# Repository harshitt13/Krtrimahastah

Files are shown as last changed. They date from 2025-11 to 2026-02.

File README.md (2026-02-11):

# Krtrimahastah: AI-Powered Low-Cost Prosthetic Hand with intuitive multi-modal control and force feedback

**Krtrimahastah** (Sanskrit for _Artificial Hand_) is an open-source, affordable, and intelligent prosthetic arm designed to bridge the gap between expensive bionic limbs and passive cosmetic devices.

By leveraging 3D printing, the ESP32 microcontroller, AI integration, and affordable hobbyist components, this project delivers a fully functional, multi-modal assistive device for under **$100 USD**.

Watch the video on YouTube: [https://youtu.be/Tq0eUJswGTI](https://youtu.be/Tq0eUJswGTI)

Watch the demonstration video on YouTube: [https://youtu.be/BNZyQIecj14](https://youtu.be/BNZyQIecj14)

---

## Table of Contents

- [Key Features](#key-features)
- [Project Overview](#project-overview)
- [Hardware Architecture](#hardware-architecture)
- [Pinout Reference](#pinout-reference)
- [System Architecture & Connection Flow](#system-architecture--connection-flow)
- [3D Model Components](#3d-model-components)
- [Wire Mapping](#wire-mapping)
- [Electrical Schematic](#electrical-schematic)
- [Control Logic](#control-logic)
- [Software Setup](#software-setup)
- [Installation & Setup](#installation--setup)
- [Usage Guide](#usage-guide)
- [File Structure](#file-structure)
- [Learning Resources](#learning-resources)
- [License](#license)
- [Disclaimer & Safety Notice](#%EF%B8%8F-disclaimer--safety-notice)
- [Contact & Support](#contact--support)

---

## Key Features

### **Multi-Modal Control System**

- **Voice Commands (Primary):** Integrated with SinricPro IoT platform for voice control via Alexa/Google Assistant
- **EMG Muscle Signals (Secondary):** Backup EMG-based control for silent/offline operation with binary toggle (Open ↔ Close)
- **Smart Home Integration:** Connect to Amazon Alexa or Google Home for hands-free gesture commands

### **Intelligent Hardware**

- **Tendon-Driven Actuation:** Bio-inspired mechanical design with 5 independent MG90s servos for anthropomorphic finger movement
- **Haptic Feedback System:** Force Sensitive Resistors (FSRs) in fingertips enable closed-loop grip control, preventing crushing of delicate objects
- **Haptic Force Sensing:** Real-time pressure monitoring (max grip force: 2000 units with safety cutoff)

### **Power Management Innovation**

- **All-Day Portability:** Power bank with optimized power splitting:
  - **High-Power Rail:** 5V for servo actuation (high current spikes)
  - **Logic Rail:** 3.3V via ESP32 regulator (low current, noise-isolated)

### **Cost-Effective Engineering**

- Built entirely with off-the-shelf hobbyist components
- FDM 3D printing for structural parts (PLA material)
- Total BOM cost under $100 USD
- Open-source firmware for transparency and community contribution

### **Safety Features**

- Pressure/tactile feedback prevents over-gripping
- Software watchdog timer (10-second timeout)
- EMG debounce protection (200ms)
- Safety state machine for graceful error handling
- Servo angle constraints to prevent mechanical damage

---

## Project Overview

### **Problem Statement**

Prosthetic limbs remain inaccessible to the majority due to prohibitive costs ($3,000-$100,000+). This project demonstrates that functional bionic devices can be built affordably using modern open-source hardware and AI.

### **Solution**

A modular, 3D-printed prosthetic hand that combines:

- **Affordable actuation:** MG90s servo motors instead of expensive linear actuators
- **Intelligent control:** AI-based language processing with offline fallback
- **Biological feedback:** FSR-based haptic sensing for dexterous manipulation
- **Energy efficiency:** Optimized power management for all-day wearability

---

## Hardware Architecture

| Component | Quantity | Function |
| :--- | :---: | :--- |
| **ESP32 DevKit V1** | 1 | Main microcontroller (32-bit dual-core, Wi-Fi/BLE) |
| **MG90s Servo Motor** | 5 | Individual finger actuators (180° range, 1.5kg torque) |
| **SinricPro Account** | 1 | IoT cloud service for voice control integration |
| **EMG Sensor Module V3.0** | 1 | Muscle signal acquisition (3-channel, 10-bit ADC) |
| **FSR402 Pressure Sensor** | 2 | Tactile feedback in thumb & index finger |
| **10K Ohm Resistors** | 2 | Volatge Divider for FSR Sensor |
| **3D Printed Parts** | — | PLA chassis (hand, phalanges, forearm cover) |
| **Servo Horns & Hardware** | — | Servo linkages & fasteners |
| **USB-C Cable & Connectors**  | — | Power delivery & debugging |
| **Breadboard & Jumper Wires** | — | Prototyping & connections |

---

## Pinout Reference

### **ESP32 GPIO Pin Allocation**

| Component | Signal Line | ESP32 GPIO | Pin Type | Notes |
| :--- | :--- | :---: | :--- | :--- |
| **SERVO: Thumb** | PWM Signal |  GPIO 13 | OUTPUT | Channel 0, PWM (0-180°) |
| **SERVO: Index** | PWM Signal |  GPIO 12 | OUTPUT | Channel 1, PWM (0-180°) |
| **SERVO: Middle**  | PWM Signal |  GPIO 14 | OUTPUT | Channel 2, PWM (0-180°) |
| **SERVO: Ring** | PWM Signal |  GPIO 27 | OUTPUT | Channel 3, PWM (0-180°) |
| **SERVO: Pinky** | PWM Signal |  GPIO 26 | OUTPUT | Channel 4, PWM (0-180°) |
| **EMG Sensor** | Analog Output |  GPIO 34 | ADC1 INPUT | 0-4095 (3.5-18V) muscle signal  |
| **FSR: Thumb Tip** | Analog Output |  GPIO 36 | ADC1 INPUT | Pressure sensing (0-2000 units) |
| **FSR: Index Tip** | Analog Output |  GPIO 39 | ADC1 INPUT | Pressure sensing (0-2000 units) |

### **Servo Angle Limits**

| Finger | Min Angle (Open) | Max Angle (Closed) | Movement Range |
| :----- | :---: | :---: | :---: |
| Thumb  | 0° | 120° | 120° |
| Index  | 0° | 175° | 175° |
| Middle | 0° | 175° | 175° |
| Ring | 0° | 175° | 175° |
| Pinky  | 0° | 175° | 175° |

---

## System Architecture & Connection Flow

### **Overall System Architecture**

```mermaid
graph TB
    subgraph "Input Layer"
        VOICE["Voice Input<br/>Alexa/Google Assistant"]
        EMG["EMG Sensor<br/>Muscle Signals"]
        FSR["FSR Sensors<br/>Tactile Feedback"]
    end

    subgraph "Processing Layer"
        ESP32["ESP32 DevKit<br/>Main Microcontroller<br/>Dual-Core 240MHz"]
        WIFI["Wi-Fi Module<br/>802.11 b/g/n"]
        SINRIC["SinricPro<br/>IoT Cloud Service"]
    end

    subgraph "Control Logic"
        FSM["State Machine<br/>5 Operating Modes"]
        SERVO_CTRL["Servo Controller<br/>PWM Generator"]
        SAFETY["Safety Module<br/>Watchdog & Limits"]
    end

    subgraph "Output Layer"
        THUMB["Thumb Servo<br/>GPIO 13"]
        INDEX["Index Servo<br/>GPIO 12"]
        MIDDLE["Middle Servo<br/>GPIO 14"]
        RING["Ring Servo<br/>GPIO 27"]
        PINKY["Pinky Servo<br/>GPIO 26"]
    end

    subgraph "Power Distribution"
        BATTERY["Power Bank"]
        SERVO_RAIL["Servo Rail (5V)<br/>High Current"]
        LOGIC_RAIL["Logic Rail (3.3V)<br/>Low Noise"]
    end

    VOICE --> SINRIC
    EMG --> ESP32
    FSR --> ESP32
    ESP32 --> WIFI
    WIFI --> SINRIC
    SINRIC --> ESP32
    ESP32 --> FSM
    FSM --> SERVO_CTRL
    FSR --> SAFETY
    SERVO_CTRL --> SAFETY
    SAFETY --> THUMB
    SAFETY --> INDEX
    SAFETY --> MIDDLE
    SAFETY --> RING
    SAFETY --> PINKY
    BATTERY --> SERVO_RAIL
    BATTERY --> LOGIC_RAIL
    SERVO_RAIL --> THUMB
    SERVO_RAIL --> INDEX
    SERVO_RAIL --> MIDDLE
    SERVO_RAIL --> RING
    SERVO_RAIL --> PINKY
    LOGIC_RAIL --> ESP32
    LOGIC_RAIL --> FSR
    SERVO_RAIL --> EMG
```

### **Control Flow & State Machine Diagram**

```mermaid
stateDiagram-v2
    [*] --> IDLE

    IDLE --> EMG_CONTROL: System Initialized

    EMG_CONTROL --> GESTURE: Voice trigger + Valid command
    EMG_CONTROL --> GESTURE: EMG muscle flex detected

    GESTURE --> EMG_CONTROL: Gesture complete

    EMG_CONTROL --> SAFETY_STOP: FSR limit exceeded<br/>OR EMG overload<br/>OR Watchdog timeout
    SAFETY_STOP --> EMG_CONTROL: User releases grip<br/>Safety reset triggered

    EMG_CONTROL --> [*]: Shutdown signal
```

### **Data Flow: Voice Command Pipeline**

```mermaid
sequenceDiagram
    User->>Google Assistant: Speak voice command<br/>("Hey Google, turn on Prosthetic Hand")
    Google Assistant->>SinricPro: Process & forward command
    SinricPro->>ESP32: Send gesture command via WebSocket
    ESP32->>ESP32: Parse mode command<br/>(e.g., "Prosthetic Hand", "peace", "point")
    ESP32->>SERVO_CTRL: Calculate target angles
    SERVO_CTRL->>THUMB: Write PWM signal (GPIO 13)
    SERVO_CTRL->>INDEX: Write PWM signal (GPIO 12)
    SERVO_CTRL->>MIDDLE: Write PWM signal (GPIO 14)
    SERVO_CTRL->>RING: Write PWM signal (GPIO 27)
    SERVO_CTRL->>PINKY: Write PWM signal (GPIO 26)
    SERVO_CTRL->>FSR: Monitor pressure (GPIO 36, 39)
    FSR->>SAFETY: Pressure threshold check
    SAFETY->>User: Haptic feedback (grip achieved)
```

### **Power Management & Rail Isolation**

```mermaid
graph LR
    BATTERY["<br/>Dual USB Output"]

    USB1["USB Port 1<br/>5V Output"]
    USB2["USB Port 2<br/>5V Output"]

    SERVO_POWER["Servo Rail Breadboard<br/>5V Direct<br/>500mA+"]
    LOGIC_POWER["Logic Rail Breadboard<br/>5V → ESP32 Regulator<br/>→ 3.3V<br/>100mA clean"]

    SERVO_DRAWS["Servo Power Draws:<br/>• Idle: 5-10mA/servo + EMG<br/>• Active: 100-200mA/servo<br/>• Peak: 500mA (all 5)"]

    LOGIC_DRAWS["Logic Power Draws:<br/>• ESP32: 80-160mA<br/>• FSR: 10-15mA<br/>• Total: ~140mA"]

    BATTERY --> USB1
    BATTERY --> USB2
    USB1 --> SERVO_POWER
    USB2 --> LOGIC_POWER
    SERVO_POWER --> SERVO_DRAWS
    LOGIC_POWER --> LOGIC_DRAWS

```

---

## 3D Model Components

### **Hand Assembly Structure**

[Hand Layout Reference (STL)](hardware/3d-models/Hand%20Layout.stl)
_Reference: Complete hand assembly layout showing all finger components and palm structure_

The prosthetic hand consists of **8 3D-printed parts** designed for FDM printing (PLA material):

| Component | File Name | Material |
| :--- | :--- | :---: |
| **Palm/Metacarpal** | `Hand.stl` | PLA |
| **Thumb Digit** | `Finger_Thumb.stl`  | PLA |
| **Index Finger** | `Finger_Index.stl`  | PLA |
| **Middle Finger** | `Finger_Middle.stl` | PLA |
| **Ring Finger** | `Finger_Ring.stl` | PLA |
| **Pinky Finger** | `Finger_Pinky.stl`  | PLA |
| **Arm Cover** | `Arm_Cover.stl` | PLA |
| **Right Hand** | `Right_Hand.stl` | PLA |

### **3D Printing Recommendations**

```
Printer Settings:
├─ Nozzle Temperature: 210°C (PLA)
├─ Bed Temperature: 60°C
├─ Layer Height: 0.2mm (0.1mm for finger tips for detail)
├─ Infill: 40% (gyroid pattern for strength/weight ratio)
├─ Support: Yes (especially for finger undercuts)
├─ Print Speed: 50mm/s
├─ Total Print Time: ~40 hours
└─ Material Weight: ~250g PLA filament
```

### **Assembly Instructions**

1. Print all components with support structures
2. Remove supports carefully (palm/finger joints are delicate)
3. Assemble fingers and attch to plam pivto points using 0.5mm fishing wire (for retarcking) and 2mm elastic string (for flexibility)
4. Use super glue attach servos in palm housing
5. Connect servo horns to finger linkages via fishing wire
6. Mount arm cover shell with servo motor peeking through rear cavity
7. Route wiring through forearm to the circuit
8. Perform mechanical range-of-motion test before powering (zeroing all the motors while fingers are opened)

---

## Wire Mapping

### **Connection Matrix: Sensors ↔ ESP32**

**Detailed wiring documentation available in:** [Wire Mapping](hardware/wiring/Wire%20Mapping%20for%20the%20Development%20of%20a%20Low-Cost%20Prosthetic%20Hand%20%281%29.xlsx)

### **Quick Wire Reference (5V Servos)**

```
┌─────────────────────────────────────────────┐
│              SERVO CONNECTIONS              │
├──────────────┬──────────┬───────────────────┤
│ Servo Motor  │ ESP32    │ Function          │
├──────────────┼──────────┼───────────────────┤
│ Thumb        │ GPIO 13  │ PWM Output        │
│ Index        │ GPIO 12  │ PWM Output        │
│ Middle       │ GPIO 14  │ PWM Output        │
│ Ring         │ GPIO 27  │ PWM Output        │
│ Pinky        │ GPIO 26  │ PWM Output        │
│ GND (All)    │ GND      │ Common ground     │
│ +5V (All)    │ +5V Rail │ Servo power rail  │
└──────────────┴──────────┴───────────────────┘
```

### **Sensor Wire Connections**

```
┌─────────────────────────────────────────────────────────────┐
│              SENSOR & INPUT CONNECTIONS                     │
├──────────────────┬──────────┬──────────┬────────────────────┤
│ Component        │ Signal   │ ESP32    │ Type               │
├──────────────────┼──────────┼──────────┼────────────────────┤
│ EMG Sensor       │ SIG      │ GPIO 34  │ Analog Input (ADC) │
│ FSR Thumb        │ SIG      │ GPIO 36  │ Analog Input (ADC) │
│ FSR Index        │ SIG      │ GPIO 39  │ Analog Input (ADC) │
│ All Sensors      │ GND      │ GND      │ Common ground      │
│ EMG Sensors (+ve)│ +5V      │ +5V Rail │ Servo power rail   │
│ Both FSR Sensors │ +3.3V    │ 3.3V     │ Logic power        │
└──────────────────┴──────────┴──────────┴────────────────────┘
```

### **SinricPro Voice Integration**

```
Alexa/Google Assistant → SinricPro Cloud → WebSocket → ESP32
│
├─ Supported Gestures: 20+ hand poses
├─ Protocol: WebSocket (persistent connection)
├─ Commands: Natural language ("open hand", "make a fist", "point")
├─ Response Time: ~200-500ms (cloud processing)
└─ Offline Fallback: EMG sensor toggle control
```

---

## Electrical Schematic

### **Schematic Diagram**

<p align="center">
  <a href="hardware/schematics/Prosthetci%20Hand%20Schematic.png">
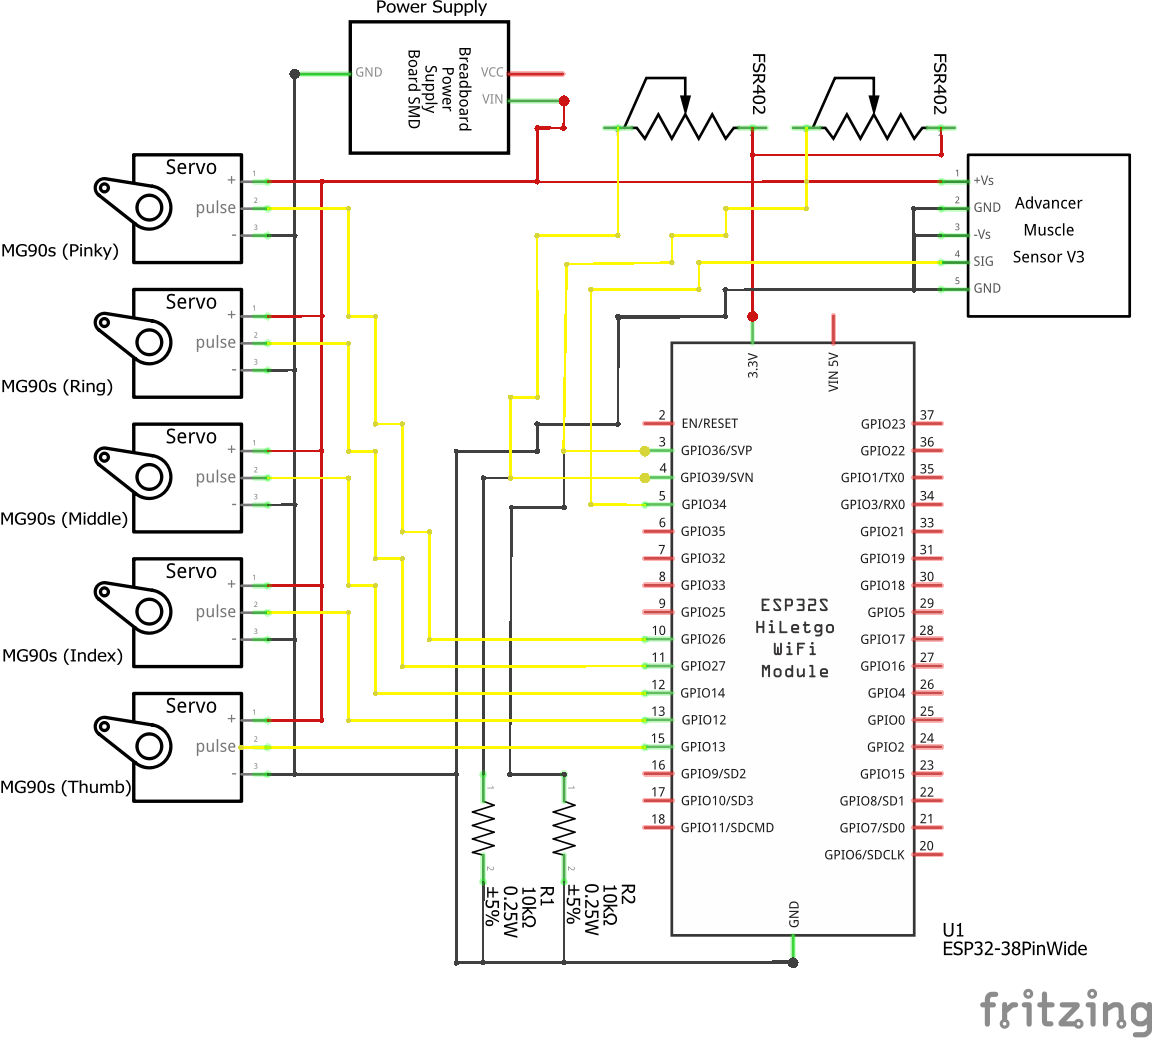
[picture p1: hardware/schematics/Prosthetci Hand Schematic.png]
    
  </a>
</p>

### **Power Distribution**

```
┌──────────────────────────────────────────────────────────────────┐
│                    POWER DISTRIBUTION SYSTEM                     │
├──────────────────────────────────────────────────────────────────┤
│                                                                  │
│  Power Bank (Dual Output)                                        │
│  ├─ USB Port 1 (5V, 3A) ──► SERVO POWER RAIL (5V, 500mA+)        │
│  │                         ├─► MG90s Servo 1 (GPIO 13)           │
│  │                         ├─► MG90s Servo 2 (GPIO 12)           │
│  │                         ├─► MG90s Servo 3 (GPIO 14)           │
│  │                         ├─► MG90s Servo 4 (GPIO 27)           │
│  │                         ├─► MG90s Servo 5 (GPIO 26)           │
│  │                         └─► EMG Sensor V3.0 (GPIO 34)         │
│  │                                                               │
│  └─ USB Port 2 (3.3V, 1A) ──► LOGIC POWER RAIL (3.3V via ESP32)  │
│                              └─ ESP32 DevKit                     │
│                                 ├─ Wi-Fi Module (SinricPro)      │
│                                 ├─ EMG Sensor V3.0               │
│                                 └─ FSR402 Sensors (GPIO 36, 39)  │
│                                                                  │
└──────────────────────────────────────────────────────────────────┘
```

### **Voltage Levels & Current Budget**

```
┌────────────────────────────────────────────────────────┐
│            POWER CONSUMPTION ANALYSIS                  │
├────────────────────────────────────────────────────────┤
│                                                        │
│ SERVO RAIL (5V):                                       │
│  • Idle (all open):        25-50mA    (~250mW)         │
│  • Single servo active:   100-150mA   (~750mW)         │
│  • All servos moving:     400-600mA   (~3W)            │
│  • Peak grip (all tight):  600-800mA  (~4W)            │
│                                                        │
│ LOGIC RAIL (3.3V @ ESP32):                             │
│  • ESP32 idle:             80-100mA                    │
│  • Wi-Fi active:          150-200mA (peak)             │
│  • EMG + FSR Sensors:      10-15mA                     │
│  • Total logic:            140-220mA                   │
│                                                        │
│ BATTERY RUNTIME (Estimated):                           │
│  • Idle (servos open):     ~100 hours                  │
│  • Mixed use (50% active): ~12-15 hours                │
│  • Heavy use (all moving): ~5-7 hours                  │
│                                                        │
└────────────────────────────────────────────────────────┘
```

---

## Control Logic

### **Operating Modes**

#### **Mode 1: EMG Toggle Control (Offline)**

- **Activation:** Muscle flex detected by EMG sensor
- **Logic:** Binary toggle (Open ↔ Close)
- **Use Case:** Rapid, frequent actions; no voice needed
- **Reliability:** High (no network dependency)

```
EMG Signal → Threshold Detection → Debounce (200ms)
  → State Toggle → Servo Movement → 2-3s Animation → Return to Idle
```

#### **Mode 2: Voice Command Control (Online)**

- **Activation:** Voice command via Alexa or Google Assistant
- **Processing Pipeline:**
  1. User speaks to Google Assistant: "Hey Google, turn on Prosthetic Hand" or "Hey Google, set prosthetic hand to Peace"
  2. SinricPro cloud processes command via WebSocket
  3. ESP32 receives gesture mode string (e.g., "fist", "peace", "point")
  4. Execute corresponding servo movement pattern
- **Supported Commands:** 20+ gestures including "Prosthetic Hand," "Point," "Peace," "Hook," "Thumbs Up," "OK," "Gun,"

#### **Mode 3: Closed-Loop Grip**

- **Purpose:** Prevent over-gripping & crushing delicate objects
- **Implementation:**
  - FSR sensors in fingertips detect force
  - Once force exceeds threshold (2000 units), grip stops tightening
  - Maintains constant pressure automatically

---

## Software Setup

### **Prerequisites**

- **Arduino IDE** ([Download](https://www.arduino.cc/en/software))
- **ESP32 Board Support** installed via Board Manager
- **SinricPro Account** (Free) - Create at [https://sinric.pro](https://sinric.pro)
- **Amazon Alexa or Google Home** device (or mobile app)
- **Wi-Fi Network** with 2.4GHz support (5GHz not recommended for ESP32)

### **Required Libraries**

Install via Arduino Library Manager (`Sketch → Include Library → Manage Libraries`):

| Library | Author | Purpose |
| :--- | :--- | :--- |
| `ESP32Servo`  | Kevin Harrington | PWM servo control for MG90s motors |
| `SinricPro` | Boris Jaeger | IoT cloud integration for voice control |
| `WebSockets`  | Markus Sattler | WebSocket communication with SinricPro  |
| `ArduinoJson` | Benoit Blanchon  | JSON parsing for SinricPro messages |

### **SinricPro Setup**

1. Create a free account at [https://sinric.pro](https://sinric.pro)

2. Create a new **Device Template** → Select "Speaker" device type

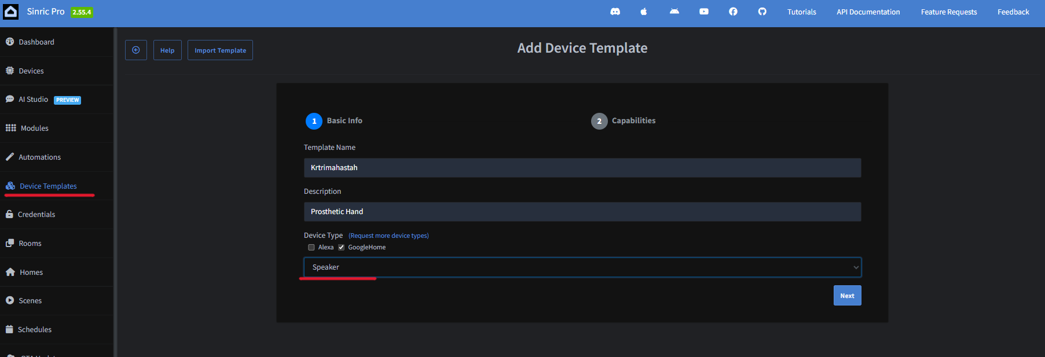
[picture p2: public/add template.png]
Add template device
   

3. Add two capabilities: "Power" & "Mode". Configure "Mode" Capability

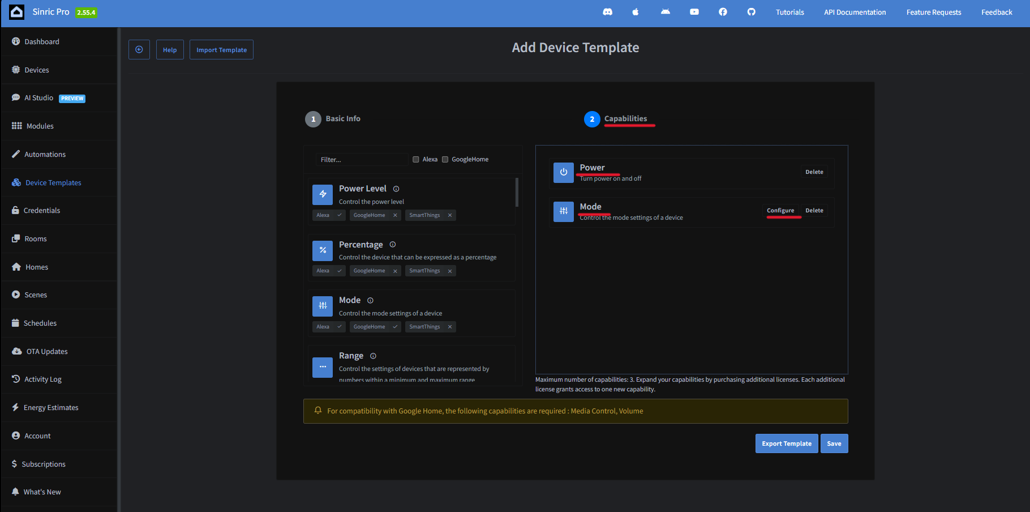
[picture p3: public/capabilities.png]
Capabilities configuration
   
   - Set "Instance Id" & "Mode Name" as shown in the photo

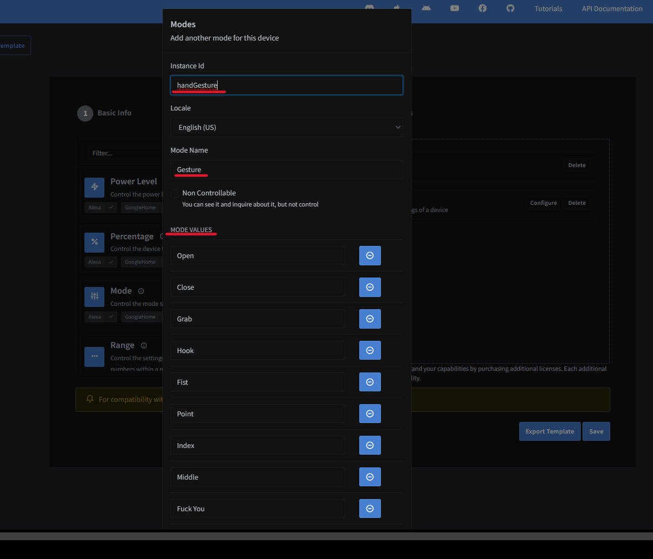
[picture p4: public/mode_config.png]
Mode configuration
     

   - Save the template

4. Create a new **Device** → Select "Krtrimahastah_Template" device type

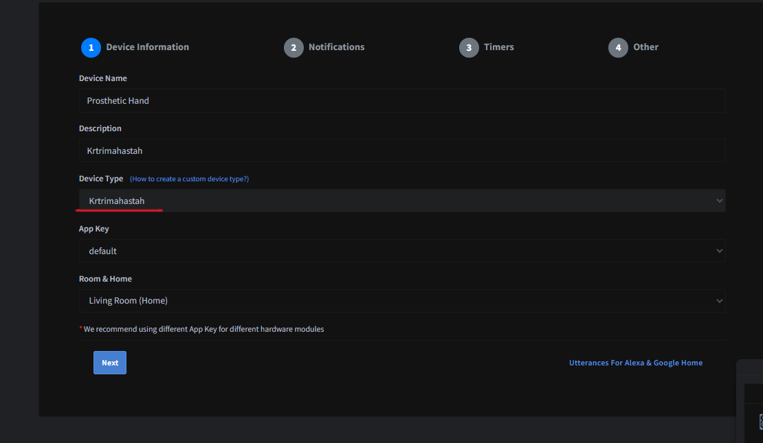
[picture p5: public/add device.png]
Add device
   

5. Note your credentials:
   - **APP_KEY** - Found in "Credentials" section
   - **APP_SECRET** - Found in "Credentials" section
   - **DEVICE_ID** - Found in your device settings

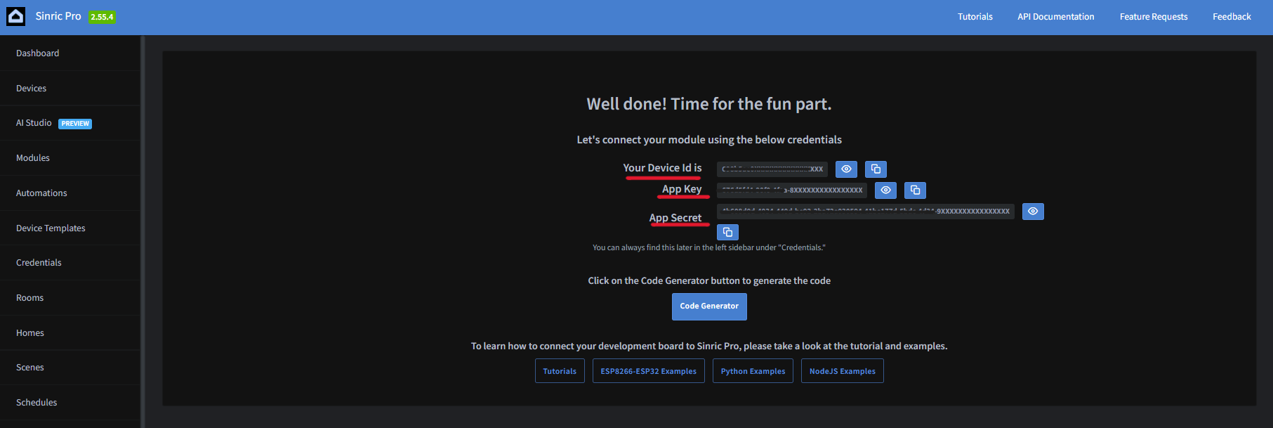
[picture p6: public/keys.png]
API Keys
     

6. Link SinricPro to **Amazon Alexa** or **Google Home**:
   - Open Alexa/Google Home app
   - Search for "SinricPro" skill and enable
   - Discover devices

7. Add credentials to firmware configuration

---

## Installation & Setup

### **Step 1: Prepare Hardware**

```bash
1. Assemble 3D-printed hand structure (see 3D Model Components)
2. Mount 5 MG90s servos inside palm housing
3. Attach servo horns to finger linkages
4. Solder power supply rails on breadboard (5V servo, 3.3V logic)
5. Wire all components according to Master Pinout (see Wire Mapping section)
6. Mount ESP32 DevKit inside arm cover
7. Connect power bank via USB cables
8. Perform visual inspection for short circuits
```

### **Step 2: Prepare Firmware**

```bash
# Clone the repository
git clone https://github.com/harshitt13/Krtrimahastah.git
cd Krtrimahastah

# Open Arduino IDE
1. File → Open → firmware/prosthetic_hand_improved.ino
2. Board: ESP32 Dev Module
3. Port: COM3 (or your ESP32 port)
```

### **Step 3: Configure Credentials**

Edit [main/main.ino](main/main.ino) and update:

```cpp
#define WIFI_SSID         "Your_Wi-Fi_SSID"
#define WIFI_PASS         "Your_Wi-Fi_Password"

#define APP_KEY           "YOUR_APP_KEY"     // From SinricPro Dashboard
#define APP_SECRET        "YOUR_APP_SECRET"  // From SinricPro Dashboard
#define DEVICE_ID         "YOUR_DEVICE_ID"   // From your SinricPro device
```

### **Step 4: Upload & Test**

```
1. Verify code (Sketch → Verify)
2. Upload to ESP32 (Sketch → Upload)
3. Open Serial Monitor (Tools → Serial Monitor, 115200 baud)
4. Press Reset button on ESP32
5. Observe startup messages and Wi-Fi connection
6. Say "Hey Google, discover devices" to find your prosthetic hand
7. Test voice commands: "Hey Google, turn on Prosthetic Hand"
8. Test EMG mode by flexing muscles
9. Verify all 5 fingers move smoothly
```

### **Step 5: Calibration**

```cpp
EMG Sensor Tuning:
├─ Flex muscle & note ADC reading
└─ Set EMG_THReshold to ADC reading

FSR Sensor Tuning:
├─ Press fingertip & note ADC reading
├─ Set FSR_LIMIT to safe threshold (default 4000)
└─ Test grip on soft object to verify cutoff

Servo Angle Tuning:
├─ Adjust MAX_TP (thumb & pinky angle)
├─ Adjust MAX_OTHERS (index, middle, ring finger angle)
└─ Test all gestures for smooth motion
```

---

## Usage Guide

### **Voice Control (via Alexa/Google Assistant)**

```
1. Say "Hey Google, turn on Prosthetic Hand" or "Hey Google, set prosthetic hand to peace"
2. SinricPro processes command and sends to ESP32
3. Hand executes the gesture smoothly
4. Stays in gesture until new command or EMG override

Supported Hey Google Commands:

Functional Gestures:
├─ "Hey Google, turn on/off Prosthetic Hand"                   → ON/OFF Prosthetic Hand
├─ "Hey Google, set prosthetic hand to Hook"                   → Hook grip (all fingers curled except thumb)
└─ "Hey Google, set prosthetic hand to Grab"                   → Grab the object (All fingers closed)

Social Gestures:
├─ "Hey Google, set prosthetic hand to Open"                   → All fingers extended
├─ "Hey Google, set prosthetic hand to Point"                  → Index finger pointing
├─ "Hey Google, set prosthetic hand to Two"                    → Peace sign (index + middle)
├─ "Hey Google, set prosthetic hand to Three"                  → Three fingers up
├─ "Hey Google, set prosthetic hand to Four"                   → Four fingers up
├─ "Hey Google, set prosthetic hand to Thumbs Up"              → Thumbs up gesture
├─ "Hey Google, set prosthetic hand to OK"                     → OK sign (thumb + index circle)
├─ "Hey Google, set prosthetic hand to Love"                   → there's no love, forget her bro
├─ "Hey Google, set prosthetic hand to Gun"                    → Finger gun
├─ "Hey Google, set prosthetic hand to Call"                   → Call me gesture
├─ "Hey Google, set prosthetic hand to Fuck Off"               → no one have enemies
└─ "Hey Google, set prosthetic hand to Pinky"                  → Pinky promise

Control:
├─ "Hey Google, turn on Hand"                                  → Enable EMG control
└─ "Hey Google, turn off Hand"                                 → Disable EMG control
```

### **EMG Control**

```
1. Ensure EMG sensor strap is worn around forearm
2. Relax arm at rest
3. Flex muscle briefly (1-2 second contraction)
4. Hand gesture toggles (Open ↔ Close)
5. No voice required; works offline

Gesture Sequence:
├─ Open → Flex → Close
├─ Close → Flex → Open
└─ Debounce: 200ms (ignores multiple quick flexes)
```

### **Emergency Stop**

```
Safety is automatic via FSR sensors:
→ If FSR detects force > 4000 units, fingers stop automatically
→ Triggers SAFETY_STOP state
→ All fingers will stop at their current position and will only move if the sensor detects less force or either it's an opening command.

Manual Reset:
→ Send "Open" command via Hey Google
→ Or use EMG sensor to toggle open
```

---

## File Structure

```
Krtrimahastah/
├── .dist/                                     # Build output (if present)
├── README.md                                  # Project documentation
├── LICENSE                                    # MIT License
├── main/
│   └── main.ino                               # Main ESP32 firmware (682 lines)
├── public/                                    # Static assets (if present)
└── hardware/
  ├── 3d-models/
  │   ├── Hand Layout.stl                     # Full assembly reference
  │   ├── Hand.stl                            # Palm structure
  │   ├── Finger_Thumb.stl                    # Thumb digit
  │   ├── Finger_Index.stl                    # Index finger
  │   ├── Finger_Middle.stl                   # Middle finger
  │   ├── Finger_Ring.stl                     # Ring finger
  │   ├── Finger_Pinky.stl                    # Pinky finger
  │   ├── Arm_Cover.stl                       # Forearm enclosure
  │   ├── Hand_print_layout.stl               # Print nesting guide
  │   └── Right_Hand.stl                      # Mirror version
  ├── schematics/
  │   └── Prosthetci Hand Schematic.png       # Circuit diagram
  └── wiring/
    └── Wire Mapping for the Development of a Low-Cost Prosthetic Hand.xlsx # Detailed pinout & connection matrix

```

---

## Learning Resources

- **ESP32 Documentation:** [https://docs.espressif.com/projects/esp-idf/](https://docs.espressif.com/projects/esp-idf/)
- **SinricPro Documentation:** [https://sinricpro.github.io/esp8266-esp32-sdk/](https://sinricpro.github.io/esp8266-esp32-sdk/)
- **Servo Motor Control:** [https://randomnerdtutorials.com/esp32-servo-motor/](https://randomnerdtutorials.com/esp32-servo-motor/)
- **Myoware Muscle Sensor User-Manual** [https://robu.in/wp-content/uploads/2019/02/Muscle-Sensor-v3-Users-Manual.pdf/](https://robu.in/wp-content/uploads/2019/02/Muscle-Sensor-v3-Users-Manual.pdf)

---

## License

This project is licensed under the **MIT License** - see the [LICENSE](LICENSE) file for details.

Permission is granted for personal, educational, and commercial use with proper attribution.

---

## ⚠️ Disclaimer & Safety Notice

**IMPORTANT:** This is a **research prototype** and **NOT a medically certified device**.

### **Usage Warnings:**

- ⚠️ Not intended for medical/therapeutic use without proper regulatory approval
- ⚠️ Strength and safety capabilities vary widely based on component quality and assembly accuracy
- ⚠️ Do not use with high-pressure/high-risk gripping tasks
- ⚠️ Servo motors can pinch fingers; always supervise use around children
- ⚠️ Battery may overheat if damaged; inspect regularly for swelling
- ⚠️ Wi-Fi connectivity may drop; EMG control serves as offline backup
- ⚠️ Test all safety features before extended use

### **Liability:**

The author and contributors assume **NO LIABILITY** for injuries, property damage, or adverse outcomes resulting from the use or misuse of this device.

---

## Contact & Support

- **GitHub Issues:** [Report bugs or request features](https://github.com/harshitt13/Krtrimahastah/issues)
- **Email:** find.harshitkushwaha@gmail.com

---

_Making prosthetics affordable, intelligent, and accessible to all._ 🤖

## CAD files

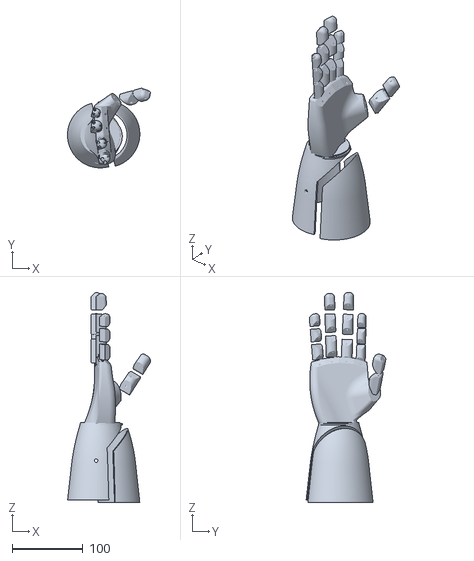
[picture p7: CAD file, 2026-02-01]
hardware/3d-models/Hand Layout.stl
117.5 x 113.1 x 297.7

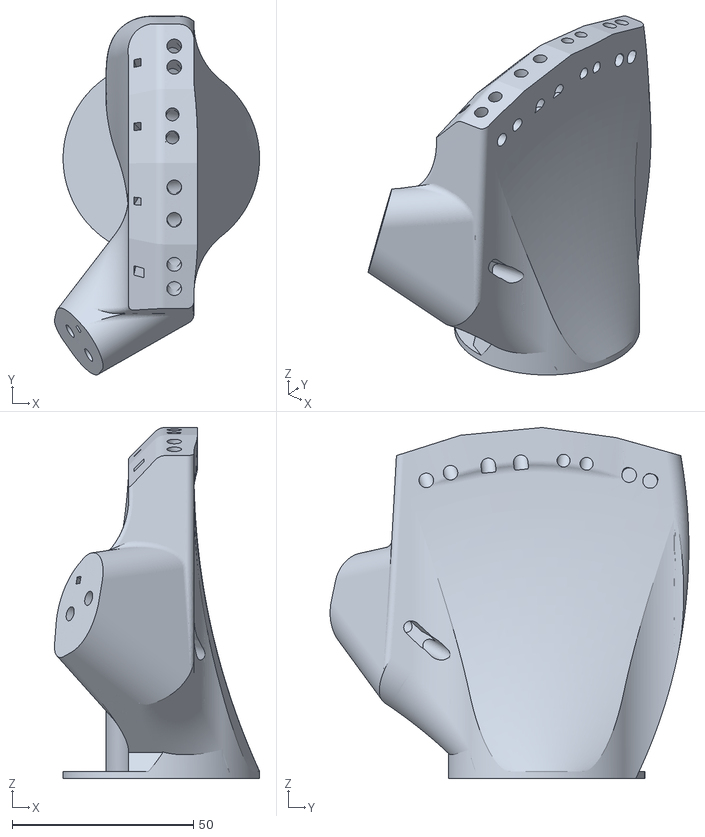
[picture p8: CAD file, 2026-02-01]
hardware/3d-models/Right_Hand.stl
56.5 x 98.9 x 96.8

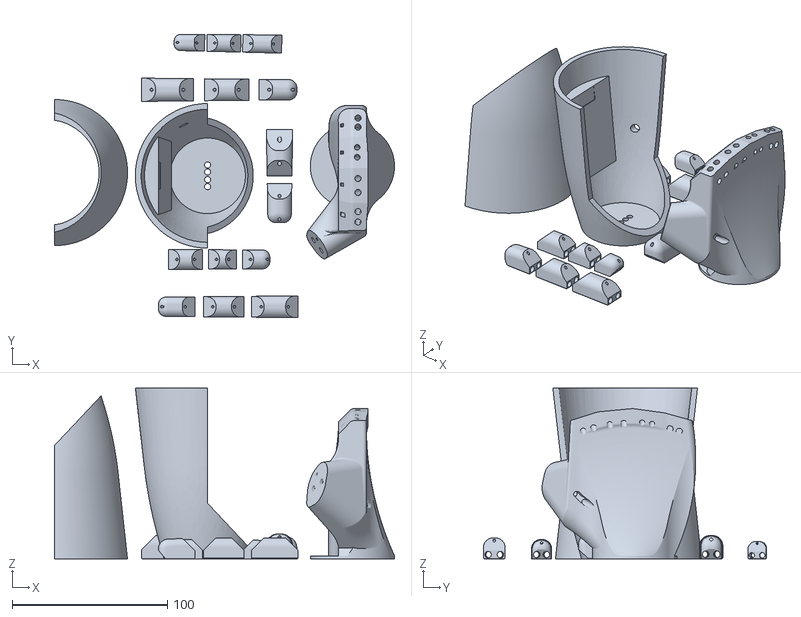
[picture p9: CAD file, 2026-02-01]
hardware/3d-models/Hand_print_layout.stl
218.8 x 182.3 x 109.9

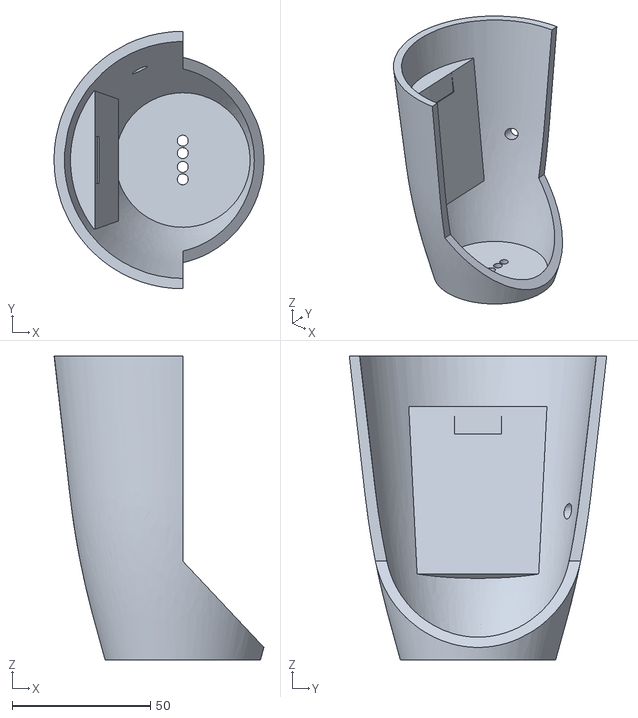
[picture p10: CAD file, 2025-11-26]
hardware/3d-models/Hand.stl
75.9 x 93.1 x 109.9

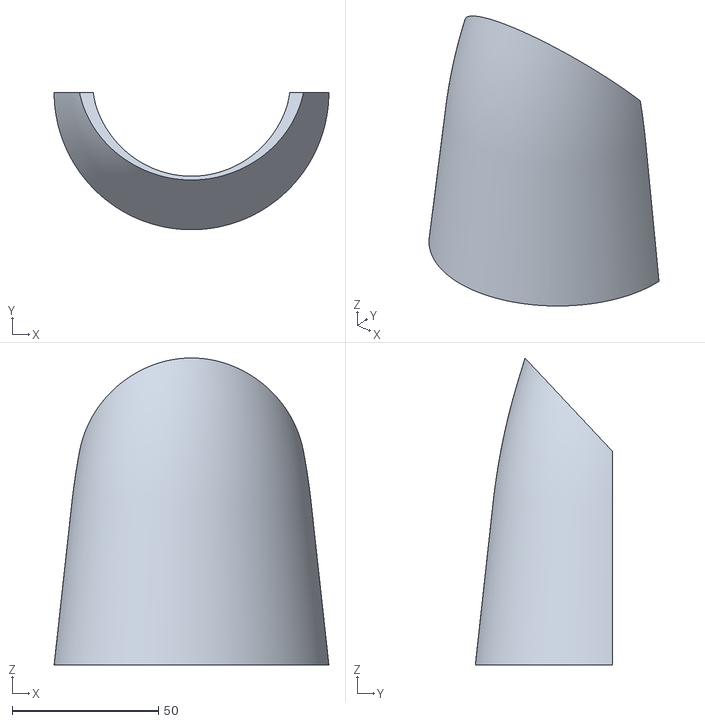
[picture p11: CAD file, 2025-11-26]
hardware/3d-models/Arm_Cover.stl
94.0 x 47.0 x 105.0

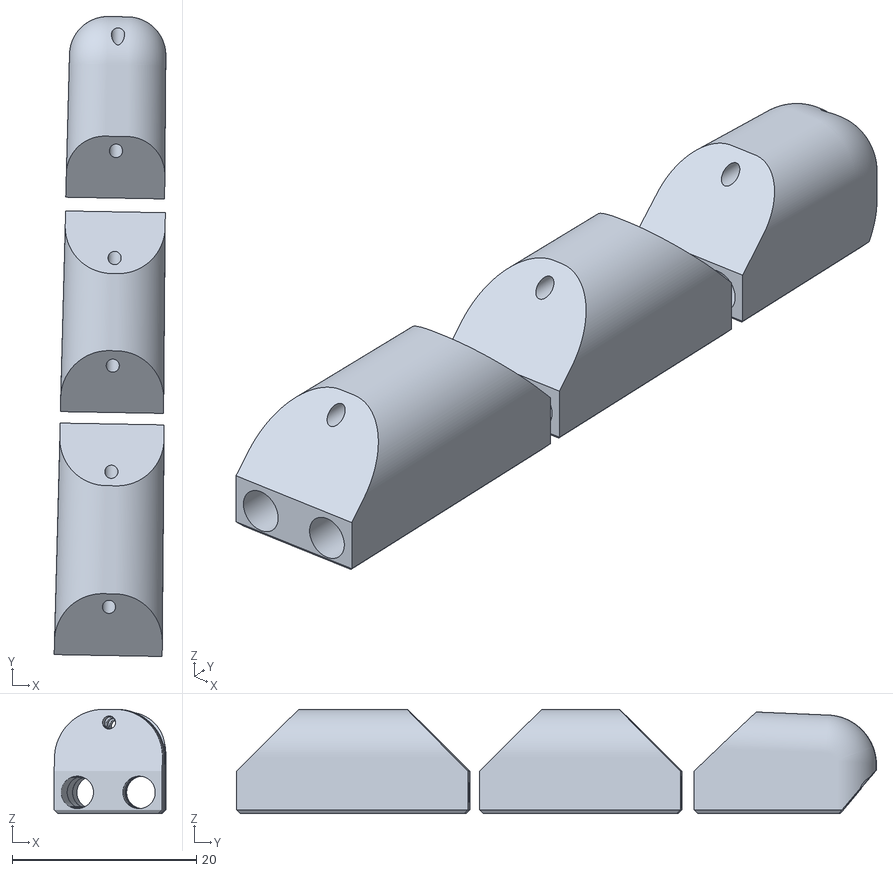
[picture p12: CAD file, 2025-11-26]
hardware/3d-models/Finger_Index.stl
12.1 x 69.4 x 11.3

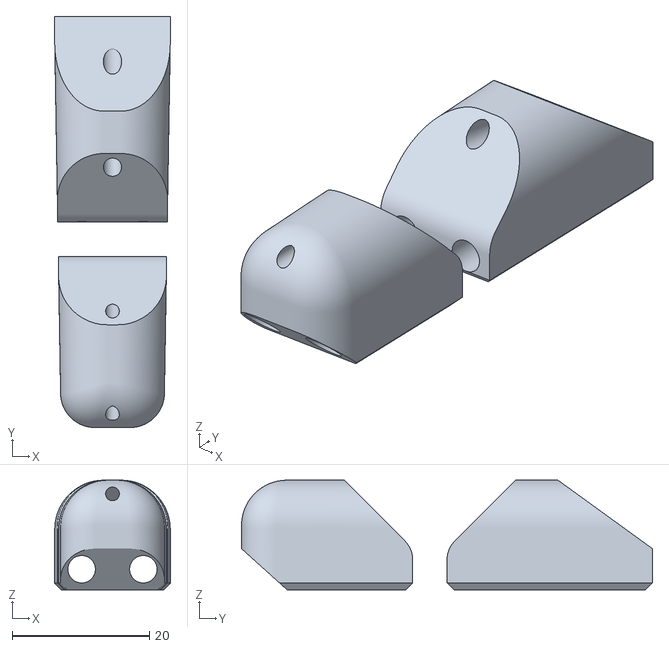
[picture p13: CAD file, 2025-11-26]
hardware/3d-models/Finger_Thumb.stl
17.0 x 60.0 x 16.0

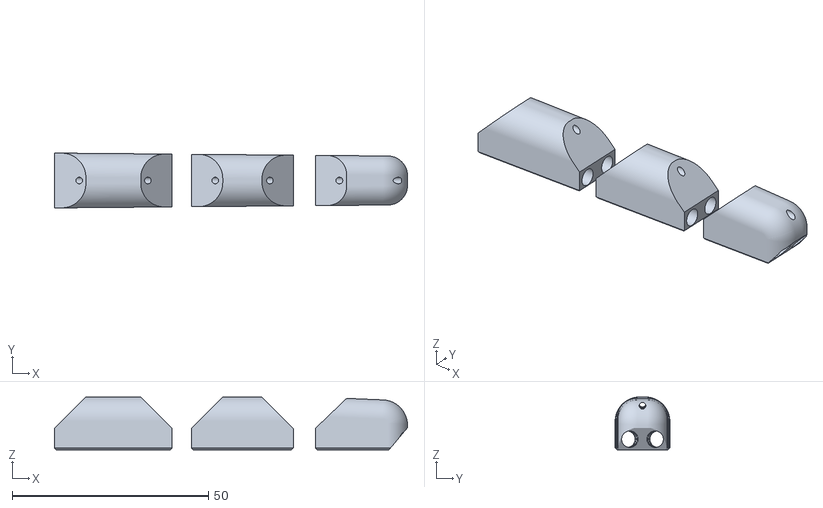
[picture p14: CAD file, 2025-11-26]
hardware/3d-models/Finger_Ring.stl
90.0 x 14.0 x 13.5

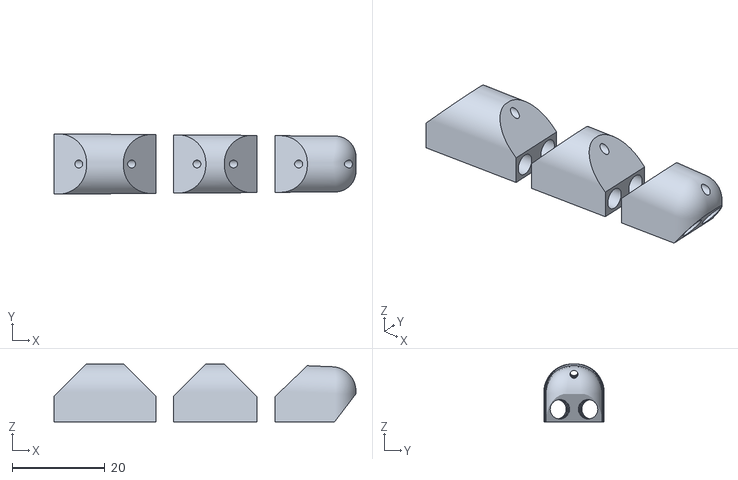
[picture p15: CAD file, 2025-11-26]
hardware/3d-models/Finger_Pinky.stl
65.2 x 13.0 x 12.5

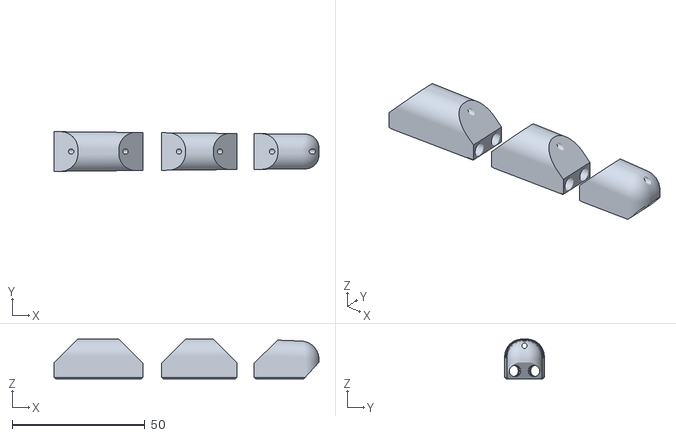
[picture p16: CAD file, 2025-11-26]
hardware/3d-models/Finger_Middle.stl
100.0 x 15.0 x 15.0

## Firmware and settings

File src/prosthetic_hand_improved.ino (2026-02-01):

#include <WiFi.h>
#include <SinricPro.h>
#include <SinricProDevice.h>
#include <SinricProSwitch.h> 
#include <ESP32Servo.h>

/* ================= USER CONFIG ================= */

#define WIFI_SSID         "YOUR_WIFI_NAME"
#define WIFI_PASS         "YOUR_WIFI_PASSWORD"
#define APP_KEY           "YOUR_APP_KEY"
#define APP_SECRET        "YOUR_APP_SECRET"

#define HAND_DEVICE_ID    "YOUR_HAND_DEVICE_ID"
#define MUSCLE_SWITCH_ID  "YOUR_MUSCLE_SWITCH_ID"

// ---------- PINS ----------
#define PIN_EMG           34
#define PIN_FSR_THUMB     36
#define PIN_FSR_INDEX     39

#define SERVO_THUMB       13
#define SERVO_INDEX       12
#define SERVO_MIDDLE      14
#define SERVO_RING        27
#define SERVO_PINKY       26

// ---------- TUNING ----------
#define EMG_OPEN_THR      60
#define EMG_CLOSE_THR     120
#define FSR_LIMIT         2000

#define SERVO_BASE_SPEED  15

#define MAX_TP            120
#define MAX_OTHERS        175

// ---------- SAFETY & STABILITY ----------
#define EMG_SAMPLE_COUNT       5     // Number of samples to average
#define FSR_SAMPLE_COUNT       3     // Number of samples to average
#define WIFI_RECONNECT_INTERVAL 30000 // 30 seconds
#define SERVO_UPDATE_INTERVAL   50   // Minimum time between servo updates (ms)
#define SAFETY_CHECK_INTERVAL   100  // How often to check safety sensors (ms)
#define EMG_DEBOUNCE_TIME      200   // Debounce time for EMG state changes (ms)
#define WATCHDOG_TIMEOUT       10000 // Reset if stuck for 10 seconds

/* ================= ENUMS & STRUCTS ================= */

enum HandState {
  STATE_IDLE,
  STATE_EMG_CONTROL,
  STATE_GESTURE,
  STATE_ANIMATION_ILY,
  STATE_ANIMATION_RPS,
  STATE_SAFETY_STOP
};

enum EmgState {
  EMG_NEUTRAL = 0,
  EMG_OPEN = -1,
  EMG_CLOSE = 1
};

struct ServoPosition {
  int thumb;
  int index;
  int middle;
  int ring;
  int pinky;
};

/* ================= GLOBAL STATE ================= */

Servo thumb, indexFinger, middle, ring, pinky;

HandState currentState = STATE_EMG_CONTROL;
EmgState emgState = EMG_NEUTRAL;
ServoPosition currentPos = {0, 0, 0, 0, 0};
ServoPosition targetPos = {0, 0, 0, 0, 0};

bool emgControlActive = true;
bool wifiConnected = false;
bool safetyOverride = false;

// ----- Timing variables -----
unsigned long lastServoUpdate = 0;
unsigned long lastSafetyCheck = 0;
unsigned long lastEmgChange = 0;
unsigned long lastWifiCheck = 0;
unsigned long lastWatchdog = 0;

// ----- I LOVE YOU animation -----
bool ilyActive = false;
int ilyStage = 0;
unsigned long ilyTimer = 0;

// ----- ROCK PAPER SCISSORS animation -----
bool rpsActive = false;
int rpsStage = 0;
int rpsChoice = 0;
unsigned long rpsTimer = 0;

// ----- Sensor buffers for averaging -----
int emgBuffer[EMG_SAMPLE_COUNT] = {0};
int fsrThumbBuffer[FSR_SAMPLE_COUNT] = {0};
int fsrIndexBuffer[FSR_SAMPLE_COUNT] = {0};
int bufferIndex = 0;

/* ================= UTILITY FUNCTIONS ================= */

// Moving average filter for EMG
int getFilteredEMG() {
  emgBuffer[bufferIndex % EMG_SAMPLE_COUNT] = analogRead(PIN_EMG);
  
  int sum = 0;
  for (int i = 0; i < EMG_SAMPLE_COUNT; i++) {
    sum += emgBuffer[i];
  }
  
  return sum / EMG_SAMPLE_COUNT;
}

// Moving average filter for FSR sensors
int getFilteredFSR(int pin, int* buffer) {
  buffer[bufferIndex % FSR_SAMPLE_COUNT] = analogRead(pin);
  
  int sum = 0;
  for (int i = 0; i < FSR_SAMPLE_COUNT; i++) {
    sum += buffer[i];
  }
  
  return sum / FSR_SAMPLE_COUNT;
}

// Check if safety sensors detect excessive force
bool checkSafety() {
  int fsrThumb = getFilteredFSR(PIN_FSR_THUMB, fsrThumbBuffer);
  int fsrIndex = getFilteredFSR(PIN_FSR_INDEX, fsrIndexBuffer);
  
  if (fsrThumb > FSR_LIMIT || fsrIndex > FSR_LIMIT) {
    Serial.println("SAFETY: Force limit exceeded!");
    return false;
  }
  
  return true;
}

// Update EMG state with debouncing
void updateEmgState() {
  int emgVal = getFilteredEMG();
  EmgState newState = EMG_NEUTRAL;
  
  if (emgVal > EMG_CLOSE_THR) {
    newState = EMG_CLOSE;
  } else if (emgVal < EMG_OPEN_THR) {
    newState = EMG_OPEN;
  }
  
  // Only change state if debounce time has passed
  if (newState != emgState && (millis() - lastEmgChange > EMG_DEBOUNCE_TIME)) {
    emgState = newState;
    lastEmgChange = millis();
    
    Serial.print("EMG State: ");
    Serial.println(emgState == EMG_CLOSE ? "CLOSE" : (emgState == EMG_OPEN ? "OPEN" : "NEUTRAL"));
  }
}

// Constrain servo values to safe ranges
ServoPosition constrainPosition(ServoPosition pos) {
  pos.thumb = constrain(pos.thumb, 0, MAX_TP);
  pos.pinky = constrain(pos.pinky, 0, MAX_TP);
  pos.index = constrain(pos.index, 0, MAX_OTHERS);
  pos.middle = constrain(pos.middle, 0, MAX_OTHERS);
  pos.ring = constrain(pos.ring, 0, MAX_OTHERS);
  
  return pos;
}

// Check if target position is reached
bool positionReached() {
  return (abs(currentPos.thumb - targetPos.thumb) < 5 &&
          abs(currentPos.index - targetPos.index) < 5 &&
          abs(currentPos.middle - targetPos.middle) < 5 &&
          abs(currentPos.ring - targetPos.ring) < 5 &&
          abs(currentPos.pinky - targetPos.pinky) < 5);
}

/* ================= SERVO CONTROL ================= */

void setTargetPosition(int t, int i, int m, int r, int p) {
  targetPos = {t, i, m, r, p};
  targetPos = constrainPosition(targetPos);
}

void updateServos() {
  unsigned long now = millis();
  
  // Rate limit servo updates
  if (now - lastServoUpdate < SERVO_UPDATE_INTERVAL) {
    return;
  }
  
  lastServoUpdate = now;
  
  // Calculate speed multiplier based on EMG state
  int stepSize = SERVO_BASE_SPEED;
  if (emgState == EMG_CLOSE) stepSize *= 2;  // Faster closing
  if (emgState == EMG_OPEN) stepSize /= 2;   // Slower opening
  
  // Smoothly move towards target
  bool moved = false;
  
  if (currentPos.thumb != targetPos.thumb) {
    currentPos.thumb += (currentPos.thumb < targetPos.thumb) ? min(stepSize, targetPos.thumb - currentPos.thumb) 
                                                               : max(-stepSize, targetPos.thumb - currentPos.thumb);
    thumb.write(currentPos.thumb);
    moved = true;
  }
  
  if (currentPos.index != targetPos.index) {
    currentPos.index += (currentPos.index < targetPos.index) ? min(stepSize, targetPos.index - currentPos.index)
                                                               : max(-stepSize, targetPos.index - currentPos.index);
    indexFinger.write(currentPos.index);
    moved = true;
  }
  
  if (currentPos.middle != targetPos.middle) {
    currentPos.middle += (currentPos.middle < targetPos.middle) ? min(stepSize, targetPos.middle - currentPos.middle)
                                                                  : max(-stepSize, targetPos.middle - currentPos.middle);
    middle.write(currentPos.middle);
    moved = true;
  }
  
  if (currentPos.ring != targetPos.ring) {
    currentPos.ring += (currentPos.ring < targetPos.ring) ? min(stepSize, targetPos.ring - currentPos.ring)
                                                            : max(-stepSize, targetPos.ring - currentPos.ring);
    ring.write(currentPos.ring);
    moved = true;
  }
  
  if (currentPos.pinky != targetPos.pinky) {
    currentPos.pinky += (currentPos.pinky < targetPos.pinky) ? min(stepSize, targetPos.pinky - currentPos.pinky)
                                                               : max(-stepSize, targetPos.pinky - currentPos.pinky);
    pinky.write(currentPos.pinky);
    moved = true;
  }
  
  if (moved) {
    lastWatchdog = millis();  // Reset watchdog on successful movement
  }
}

/* ================= BASIC POSES ================= */

void poseOpen()      { setTargetPosition(0, 0, 0, 0, 0); }
void poseRelax()     { setTargetPosition(20, 20, 20, 20, 20); }
void poseRock()      { setTargetPosition(MAX_TP, MAX_OTHERS, MAX_OTHERS, MAX_OTHERS, MAX_TP); }
void posePaper()     { setTargetPosition(0, 0, 0, 0, 0); }
void poseScissors()  { setTargetPosition(MAX_TP, 0, 0, MAX_OTHERS, MAX_TP); }

// Functional gestures
void poseHook()      { setTargetPosition(0, 150, 150, 150, 150); }
void posePinch()     { setTargetPosition(MAX_TP, 140, MAX_OTHERS, MAX_OTHERS, MAX_TP); }
void poseTripod()    { setTargetPosition(100, 120, 120, MAX_OTHERS, MAX_TP); }

// Social gestures
void posePoint()     { setTargetPosition(MAX_TP, 0, MAX_OTHERS, MAX_OTHERS, MAX_TP); }
void poseMiddle()    { setTargetPosition(MAX_TP, MAX_OTHERS, 0, MAX_OTHERS, MAX_TP); }
void posePeace()     { setTargetPosition(MAX_TP, 0, 0, MAX_OTHERS, MAX_TP); }
void poseGun()       { setTargetPosition(0, 0, MAX_OTHERS, MAX_OTHERS, MAX_TP); }
void poseRockNRoll() { setTargetPosition(0, 0, MAX_OTHERS, MAX_OTHERS, 0); }
void poseCall()      { setTargetPosition(0, MAX_OTHERS, MAX_OTHERS, MAX_OTHERS, 0); }
void poseThumbsUp()  { setTargetPosition(0, MAX_OTHERS, MAX_OTHERS, MAX_OTHERS, MAX_TP); }
void poseOK()        { setTargetPosition(120, 140, 0, 0, 0); }
void poseLove()      { setTargetPosition(0, 0, MAX_OTHERS, MAX_OTHERS, 0); }
void poseThree()     { setTargetPosition(MAX_TP, 0, 0, 0, MAX_TP); }
void posePinky()     { setTargetPosition(MAX_TP, MAX_OTHERS, MAX_OTHERS, MAX_OTHERS, 0); }

// ILY animation poses
void pose_I() { setTargetPosition(120, 175, 175, 175, 0); }
void pose_L() { setTargetPosition(0, 0, 175, 175, 120); }
void pose_Y() { setTargetPosition(0, 175, 175, 175, 0); }

/* ================= STATE MACHINE ================= */

void enterSafetyStop() {
  Serial.println("STATE: SAFETY_STOP");
  currentState = STATE_SAFETY_STOP;
  safetyOverride = true;
  poseOpen();  // Open hand immediately
}

void enterIdleState() {
  Serial.println("STATE: IDLE");
  currentState = STATE_IDLE;
  poseRelax();
}

void enterEmgControl() {
  Serial.println("STATE: EMG_CONTROL");
  currentState = STATE_EMG_CONTROL;
}

void enterGesture() {
  Serial.println("STATE: GESTURE");
  currentState = STATE_GESTURE;
}

/* ================= I LOVE YOU ENGINE ================= */

void startILoveYou() {
  ilyActive = true;
  ilyStage = 0;
  ilyTimer = millis();
  currentState = STATE_ANIMATION_ILY;
  pose_I();
  Serial.println("Starting I Love You animation");
}

void handleILoveYouSequence() {
  if (!ilyActive) return;
  
  // Cancel on safety trigger or EMG open signal
  if (!checkSafety() || emgState == EMG_OPEN) {
    Serial.println("ILY animation cancelled");
    ilyActive = false;
    currentState = STATE_EMG_CONTROL;
    poseOpen();
    return;
  }
  
  unsigned long now = millis();
  if (now - ilyTimer < 1000) return;
  
  // Wait for position to be reached before advancing
  if (!positionReached()) return;
  
  ilyTimer = now;
  ilyStage++;
  
  if (ilyStage == 1) {
    pose_L();
  } else if (ilyStage == 2) {
    pose_Y();
  } else {
    Serial.println("ILY animation complete");
    ilyActive = false;
    currentState = STATE_EMG_CONTROL;
  }
}

/* ================= RPS ENGINE ================= */

void startRPS() {
  rpsActive = true;
  rpsStage = 0;
  rpsChoice = random(0, 3);
  rpsTimer = millis();
  currentState = STATE_ANIMATION_RPS;
  Serial.print("Starting RPS animation - choice: ");
  Serial.println(rpsChoice == 0 ? "ROCK" : (rpsChoice == 1 ? "PAPER" : "SCISSORS"));
}

void handleRPSSequence() {
  if (!rpsActive) return;
  
  // Cancel on safety trigger or EMG open signal
  if (!checkSafety() || emgState == EMG_OPEN) {
    Serial.println("RPS animation cancelled");
    rpsActive = false;
    currentState = STATE_EMG_CONTROL;
    poseOpen();
    return;
  }
  
  unsigned long now = millis();
  if (now - rpsTimer < 300) return;
  
  // Wait for position to be reached before advancing
  if (!positionReached()) return;
  
  rpsTimer = now;
  rpsStage++;
  
  // Bounce animation (3 times)
  if (rpsStage <= 6) {
    if (rpsStage % 2 == 0) {
      poseRock();
    } else {
      setTargetPosition(80, 140, 140, 140, 80);
    }
    return;
  }
  
  // Final reveal
  if (rpsStage == 7) {
    if (rpsChoice == 0) poseRock();
    else if (rpsChoice == 1) posePaper();
    else poseScissors();
    return;
  }
  
  Serial.println("RPS animation complete");
  rpsActive = false;
  currentState = STATE_EMG_CONTROL;
}

/* ================= WIFI MANAGEMENT ================= */

void checkWifiConnection() {
  unsigned long now = millis();
  
  if (now - lastWifiCheck < WIFI_RECONNECT_INTERVAL) return;
  lastWifiCheck = now;
  
  if (WiFi.status() != WL_CONNECTED && wifiConnected) {
    Serial.println("WiFi disconnected, attempting reconnect...");
    wifiConnected = false;
  }
  
  if (WiFi.status() != WL_CONNECTED) {
    WiFi.begin(WIFI_SSID, WIFI_PASS);
    delay(100);
  } else if (!wifiConnected) {
    Serial.println("WiFi reconnected!");
    wifiConnected = true;
  }
}

/* ================= SINRIC CALLBACKS ================= */

bool onSetMode(const String&, const String&, String& mode) {
  mode.toLowerCase();
  Serial.print("Gesture command received: ");
  Serial.println(mode);
  
  // Animation commands
  if (mode == "play rock paper scissors" || mode == "rock paper scissors") {
    startRPS();
    return true;
  }
  
  if (mode == "i love you") {
    startILoveYou();
    return true;
  }
  
  // Stop animations and enter gesture mode
  ilyActive = false;
  rpsActive = false;
  emgControlActive = false;
  enterGesture();
  
  // Functional gestures
  if (mode == "grab" || mode == "fist" || mode == "close") {
    poseRock();
  }
  else if (mode == "hook") {
    poseHook();
  }
  else if (mode == "pinch") {
    posePinch();
  }
  else if (mode == "tripod") {
    poseTripod();
  }
  // Social gestures
  else if (mode == "open" || mode == "five" || mode == "paper") {
    poseOpen();
  }
  else if (mode == "relax") {
    poseRelax();
  }
  else if (mode == "point" || mode == "index" || mode == "one") {
    posePoint();
  }
  else if (mode == "middle" || mode == "fuck" || mode == "fuck you" || mode == "fuck off") {
    poseMiddle();
  }
  else if (mode == "peace" || mode == "victory" || mode == "two" || mode == "scissor" || mode == "scissors") {
    posePeace();
  }
  else if (mode == "gun" || mode == "l" || mode == "l sign" || mode == "loser") {
    poseGun();
  }
  else if (mode == "rock" || mode == "rock n roll" || mode == "rock and roll") {
    poseRockNRoll();
  }
  else if (mode == "call" || mode == "y" || mode == "y sign") {
    poseCall();
  }
  else if (mode == "thumbs up" || mode == "like") {
    poseThumbsUp();
  }
  else if (mode == "ok" || mode == "okay") {
    poseOK();
  }
  else if (mode == "love") {
    poseLove();
  }
  else if (mode == "pinky") {
    posePinky();
  }
    else if (mode == "four") {
    poseFour();
  }
  else if (mode == "three") {
    poseThree();
  }
  else {
    Serial.println("Unknown gesture command");
    return false;
  }
  
  return true;
}

bool onPowerState(const String&, bool &state) {
  emgControlActive = state;
  Serial.print("EMG Control: ");
  Serial.println(state ? "ENABLED" : "DISABLED");
  
  if (state) {
    enterEmgControl();
  } else {
    enterIdleState();
  }
  
  return true;
}

/* ================= SETUP ================= */

void setup() {
  Serial.begin(115200);
  Serial.println("\n\n=== Prosthetic Hand Control Starting ===");
  
  randomSeed(analogRead(0));
  
  // Initialize PWM timers
  ESP32PWM::allocateTimer(0);
  ESP32PWM::allocateTimer(1);
  ESP32PWM::allocateTimer(2);
  ESP32PWM::allocateTimer(3);
  
  // Attach servos
  Serial.println("Attaching servos...");
  thumb.attach(SERVO_THUMB);
  indexFinger.attach(SERVO_INDEX);
  middle.attach(SERVO_MIDDLE);
  ring.attach(SERVO_RING);
  pinky.attach(SERVO_PINKY);
  
  // Initialize to open position
  poseOpen();
  delay(100);
  updateServos();  // Force immediate update
  
  Serial.println("Servos initialized");
  
  // Initialize sensor buffers
  for (int i = 0; i < EMG_SAMPLE_COUNT; i++) {
    emgBuffer[i] = analogRead(PIN_EMG);
  }
  for (int i = 0; i < FSR_SAMPLE_COUNT; i++) {
    fsrThumbBuffer[i] = analogRead(PIN_FSR_THUMB);
    fsrIndexBuffer[i] = analogRead(PIN_FSR_INDEX);
  }
  
  // WiFi connection
  Serial.print("Connecting to WiFi: ");
  Serial.println(WIFI_SSID);
  
  WiFi.begin(WIFI_SSID, WIFI_PASS);
  unsigned long t0 = millis();
  
  while (WiFi.status() != WL_CONNECTED && millis() - t0 < 10000) {
    delay(300);
    Serial.print(".");
  }
  Serial.println();
  
  if (WiFi.status() == WL_CONNECTED) {
    wifiConnected = true;
    Serial.println("WiFi connected!");
    Serial.print("IP Address: ");
    Serial.println(WiFi.localIP());
    
    // Initialize SinricPro
    SinricProDevice &hand = SinricPro[HAND_DEVICE_ID];
    hand.onSetMode("handGesture", onSetMode);
    
    SinricProSwitch &muscle = SinricPro[MUSCLE_SWITCH_ID];
    muscle.onPowerState(onPowerState);
    
    SinricPro.begin(APP_KEY, APP_SECRET);
    Serial.println("SinricPro initialized");
  } else {
    wifiConnected = false;
    emgControlActive = true;
    Serial.println("WiFi connection failed - running in offline mode");
  }
  
  lastWatchdog = millis();
  Serial.println("=== Setup Complete ===\n");
}

/* ================= MAIN LOOP ================= */

void loop() {
  unsigned long now = millis();
  
  // Watchdog check
  if (now - lastWatchdog > WATCHDOG_TIMEOUT) {
    Serial.println("WATCHDOG: System appears stuck, resetting to safe state");
    enterSafetyStop();
    lastWatchdog = now;
  }
  
  // Update sensor buffer index
  bufferIndex++;
  
  // Handle WiFi
  if (wifiConnected) {
    SinricPro.handle();
    checkWifiConnection();
  }
  
  // Update EMG state
  updateEmgState();
  
  // Safety check
  if (now - lastSafetyCheck > SAFETY_CHECK_INTERVAL) {
    lastSafetyCheck = now;
    
    if (!checkSafety() && currentState != STATE_SAFETY_STOP) {
      enterSafetyStop();
    } else if (safetyOverride && checkSafety()) {
      // Clear safety override after force is removed
      safetyOverride = false;
      enterEmgControl();
    }
  }
  
  // State machine
  switch (currentState) {
    case STATE_ANIMATION_RPS:
      handleRPSSequence();
      break;
      
    case STATE_ANIMATION_ILY:
      handleILoveYouSequence();
      break;
      
    case STATE_EMG_CONTROL:
      if (emgControlActive && !safetyOverride) {
        if (emgState == EMG_CLOSE) {
          poseRock();
        } else if (emgState == EMG_OPEN) {
          poseOpen();
        }
      }
      break;
      
    case STATE_SAFETY_STOP:
      // Remain stopped until safety clears
      break;
      
    case STATE_IDLE:
    case STATE_GESTURE:
      // Do nothing, waiting for commands
      break;
  }
  
  // Update servos smoothly
  updateServos();
  
  // Small delay to prevent excessive loop speed
  delay(10);
}

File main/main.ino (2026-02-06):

/*
 * ====================================================================
 * PROSTHETIC HAND - HYBRID CONTROL (Voice + Muscle + Global Safety)
 * ====================================================================
 * Priority Hierarchy:
 * 1. FSR Safety (Global Brake - Stops ALL fingers on contact)
 * 2. Sinric Pro (Voice Command - pauses EMG for 3s)
 * 3. EMG Sensor (Muscle Control - default state)
 */

#include <WiFi.h>
#include <SinricPro.h>
#include <SinricProSpeaker.h>
#include <ESP32Servo.h>

// ======================= CONFIGURATION =======================

#define WIFI_SSID         "WIFI_SSID"
#define WIFI_PASS         "WIFI_PASS"
#define APP_KEY           "APP_KEY"
#define APP_SECRET        "APP_SECRET"
#define DEVICE_ID         "DEVICE_ID"
#define MODE_INSTANCE     "handGesture" 

// --- SERVO PINS ---
#define PIN_THUMB   13
#define PIN_INDEX   12
#define PIN_MIDDLE  14
#define PIN_RING    27
#define PIN_PINKY   26

// --- SENSOR PINS ---
#define PIN_EMG       34  // Muscle Sensor
#define PIN_FSR_THUMB 36  // Pressure Sensor Thumb (VP)
#define PIN_FSR_INDEX 39  // Pressure Sensor Index (VN)

// --- THRESHOLDS ---
#define EMG_THRESHOLD     700  
#define FSR_LIMIT         4000  // Adjust this: Higher = harder squeeze allowed
#define EMG_PAUSE_TIME    3000  

// --- SERVO LIMITS ---
#define SERVO_MIN   0
#define MAX_TP      120 // Thumb/Pinky max
#define MAX_OTHERS  175 // Remaining Fingers max

// ======================= GLOBAL VARS =======================

Servo thumb, indexFinger, middle, ring, pinky;

struct HandPosition {
  int thumb;
  int index;
  int middle;
  int ring;
  int pinky;
};

HandPosition currentPos = {0, 0, 0, 0, 0};
HandPosition targetPos  = {0, 0, 0, 0, 0};

bool powerState = true;
unsigned long lastSinricActionTime = 0; 
const int stepSize = 15;

// ======================= SERVO LOGIC =======================

void setTargetPosition(int t, int i, int m, int r, int p) {
  targetPos.thumb = t;
  targetPos.index = i;
  targetPos.middle = m;
  targetPos.ring = r;
  targetPos.pinky = p;
}

void updateServos() {
  // Simple function to move servos incrementally toward target
  if (currentPos.thumb != targetPos.thumb) {
    currentPos.thumb += constrain(targetPos.thumb - currentPos.thumb, -stepSize, stepSize);
    thumb.write(currentPos.thumb);
  }
  if (currentPos.index != targetPos.index) {
    currentPos.index += constrain(targetPos.index - currentPos.index, -stepSize, stepSize);
    indexFinger.write(currentPos.index);
  }
  if (currentPos.middle != targetPos.middle) {
    currentPos.middle += constrain(targetPos.middle - currentPos.middle, -stepSize, stepSize);
    middle.write(currentPos.middle);
  }
  if (currentPos.ring != targetPos.ring) {
    currentPos.ring += constrain(targetPos.ring - currentPos.ring, -stepSize, stepSize);
    ring.write(currentPos.ring);
  }
  if (currentPos.pinky != targetPos.pinky) {
    currentPos.pinky += constrain(targetPos.pinky - currentPos.pinky, -stepSize, stepSize);
    pinky.write(currentPos.pinky);
  }
}

// ======================= POSE DEFINITIONS =======================

void poseOpen()      { setTargetPosition(0, 0, 0, 0, 0); }
void poseRelax()     { setTargetPosition(20, 20, 20, 20, 20); }
void poseClose()     { setTargetPosition(MAX_TP, MAX_OTHERS, MAX_OTHERS, MAX_OTHERS, MAX_TP); } 
void poseOK()        { setTargetPosition(120, 140, 0, 0, 0); }
void poseHook()      { setTargetPosition(0, 150, 150, 150, 150); }
void posePoint()     { setTargetPosition(MAX_TP, 0, MAX_OTHERS, MAX_OTHERS, MAX_TP); }
void poseTwo()       { setTargetPosition(MAX_TP, 0, 0, MAX_OTHERS, MAX_TP); }
void poseThree()     { setTargetPosition(MAX_TP, 0, 0, 0, MAX_TP); }
void poseFour()      { setTargetPosition(MAX_TP, 0, 0, 0, 0); }
void poseCall()      { setTargetPosition(0, MAX_OTHERS, MAX_OTHERS, MAX_OTHERS, 0); }
void posePinky()     { setTargetPosition(MAX_TP, MAX_OTHERS, MAX_OTHERS, MAX_OTHERS, 0); }
void poseThumbsUp()  { setTargetPosition(0, MAX_OTHERS, MAX_OTHERS, MAX_OTHERS, MAX_TP); }
void poseFuckYou()   { setTargetPosition(MAX_TP, MAX_OTHERS, 0, MAX_OTHERS, MAX_TP); }
void poseGun()       { setTargetPosition(0, 0, MAX_OTHERS, MAX_OTHERS, MAX_TP); }

// ======================= SENSOR & PLOTTING LOGIC =======================

// Function to plot data on Serial Plotter
void plotSensorData() {
  int emg = analogRead(PIN_EMG);
  int fsrThumb = analogRead(PIN_FSR_THUMB);
  int fsrIndex = analogRead(PIN_FSR_INDEX);

  Serial.print("EMG:");
  Serial.print(emg);
  Serial.print(",");
  
  Serial.print("EMG_Threshold:");
  Serial.print(EMG_THRESHOLD);
  Serial.print(",");

  Serial.print("FSR_Thumb:");
  Serial.print(fsrThumb);
  Serial.print(",");

  Serial.print("FSR_Index:");
  Serial.print(fsrIndex);
  Serial.print(",");

  Serial.print("FSR_Limit:");
  Serial.println(FSR_LIMIT);
}

void checkSensors() {
  // DETERMINE INTENDED MOVEMENT (EMG or Voice)
  // Check if Voice Command is active (pausing EMG)
  bool voiceActive = (millis() - lastSinricActionTime < EMG_PAUSE_TIME);

  if (!voiceActive) {
     int emgVal = analogRead(PIN_EMG) - 3300;
     if (emgVal > EMG_THRESHOLD) {
        poseClose(); // User wants to close
     } else {
        poseOpen();  // User wants to open
     }
  }

  // FSR GLOBAL SAFETY BRAKE
  int fsrThumbVal = analogRead(PIN_FSR_THUMB);
  int fsrIndexVal = analogRead(PIN_FSR_INDEX);
  bool pressureDetected = (fsrThumbVal > FSR_LIMIT) || (fsrIndexVal > FSR_LIMIT);

  if (pressureDetected) {
      if (targetPos.thumb > currentPos.thumb)   targetPos.thumb = currentPos.thumb;
      if (targetPos.index > currentPos.index)   targetPos.index = currentPos.index;
      if (targetPos.middle > currentPos.middle) targetPos.middle = currentPos.middle;
      if (targetPos.ring > currentPos.ring)     targetPos.ring = currentPos.ring;
      if (targetPos.pinky > currentPos.pinky)   targetPos.pinky = currentPos.pinky;
  }
}

// ======================= SINRICPRO CALLBACKS =======================

bool onPowerState(const String &deviceId, bool &state) {
  Serial.printf("Power: %s \r\n", state ? "ON" : "OFF");
  powerState = state;
  if (state) poseRelax(); else poseOpen();
  lastSinricActionTime = millis(); 
  return true;
}
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

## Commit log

2025-11-26 Refactor code structure for improved readability and maintainability
    [Arm_Cover.stl, Finger_Index.stl, Finger_Middle.stl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]
2025-11-26 liscence updaetd
    [Arm_Cover.stl, Finger_Index.stl, Finger_Middle.stl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]
2026-02-01 Refactor prosthetic hand control code: migrate to src directory, update FSR pin assignments, and enhance gesture handling
2026-02-01 [ImgBot] Optimize images
    /hardware/schematics/Prosthetci Hand Schematic.png -- 184.52kb -> 140.03kb (24.11%)
2026-02-01 refactor prosthetci hand
    [Wire Mapping for the Development of a Low-Cost Prosthetic Hand.xlsx]
2026-02-03 refine README for clarity; update voice command descriptions and power bank details
2026-02-06 refine README for accuracy; update EMG sensor voltage range, power draw details, and gesture command descriptions
2026-02-07 refine README for clarity; update wiring documentation link and enhance schematic section with image
2026-02-07 refine README for accuracy; update wiring diagram to include EMG Sensor V3.0 and correct servo connections
2026-02-09 excel updated
    [Wire Mapping for the Development of a Low-Cost Prosthetic Hand.xlsx]
2026-02-10 [ImgBot] Optimize images
    *Total -- 600.25kb -> 438.05kb (27.02%)
    /hardware/img/capabilities.png -- 168.44kb -> 119.36kb (29.14%)
    /hardware/img/mode config.png -- 96.25kb -> 69.19kb (28.11%)
    /hardware/img/add device.png -- 38.92kb -> 28.00kb (28.07%)
    /hardware/img/add template.png -- 112.15kb -> 81.48kb (27.35%)
    /hardware/schematics/Prosthetci Hand Schematic.png -- 184.49kb -> 140.03kb (24.1%)
2026-02-10 Refactor README.md to enhance clarity and organization of hardware components and assembly instructions
